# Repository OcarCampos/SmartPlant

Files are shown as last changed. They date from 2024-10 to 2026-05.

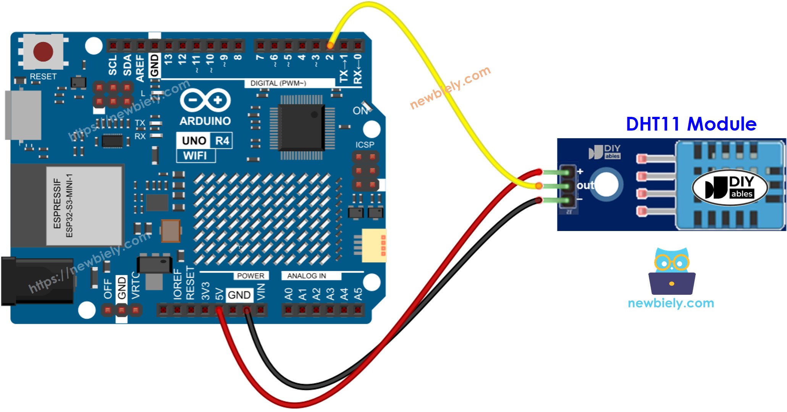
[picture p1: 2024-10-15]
Diagrams/arduino-uno-r4-dht11-module-wiring-diagram.jpg

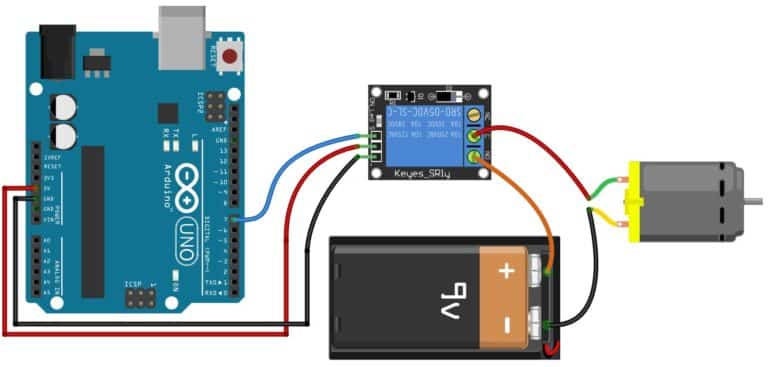
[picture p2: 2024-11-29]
Diagrams/ArduinoRelay.jpg

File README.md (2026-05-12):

# SmartPlant - Automated Garden Monitoring System




An Arduino-based garden monitoring and automated watering system. This project uses various sensors to monitor plant health and environmental conditions, with data visualization through ThingSpeak and a smart automated watering functionality.

## Table of Contents

- [Features](#features)
- [Project Status](#project-status)
- [Hardware and Software](#hardware-and-software)
  - [Hardware Requirements](#hardware-requirements)
  - [Software Dependencies](#software-dependencies)
- [Getting Started](#getting-started)
  - [Prerequisites](#prerequisites)
  - [Installation](#installation)
- [Hardware Setup](#hardware-setup)
  - [Pin Configuration](#pin-configuration)
  - [Wiring Diagrams](#wiring-diagrams)
- [How It Works](#how-it-works)
  - [Sensor Monitoring](#sensor-monitoring)
  - [Smart Watering Logic](#smart-watering-logic)
  - [ThingSpeak Integration](#thingspeak-integration)
- [Project Structure](#project-structure)
- [Development and Testing](#development-and-testing)
- [3D Printable Cases](#3d-printable-cases)
- [Contributing](#contributing)
- [License](#license)

## Features

- **Environment Monitoring**: Real-time tracking of temperature, humidity, soil moisture, and light conditions.
- **Automated Watering**: Smart watering system that activates a water pump based on soil moisture levels.
- **Data Display**: Live sensor data shown on a 16x2 LCD screen.
- **Remote Monitoring**: WiFi connectivity to send data to the ThingSpeak platform for visualization and analysis.
- **Smart Watering Cycles**: Implements timed watering cycles with absorption periods to prevent overwatering.

## Project Status

This project is considered complete and functional. All features have been implemented and tested.

**SmartPlant v2** (branch: `main`, file: `SmartPlantv2.ino`) is currently in active development and testing. It introduces a robust Arduino Nano-based monitoring station with improved sensor hardware (TEMT6000, AHT10, capacitive soil moisture) for bench validation before full deployment.

We have recently added **SmartPlantv2-uno.ino** which integrates the improved v2 sensors with the Arduino Uno R4 WiFi to report data directly to ThingSpeak, omitting the LCD and water pump for a streamlined monitoring experience.

The latest production-ready field device is **SmartPlantv2-ESP32c.ino**, designed for the ultra-compact ESP32-C3 Super Mini. This version utilizes Deep Sleep for power efficiency, features a robust debug mode, and uses an inverted sinking-LED logic for physical status indication.

## Hardware and Software

### Hardware Requirements

| Component | Purpose |
| --- | --- |
| Arduino Uno R4 WiFi | Microcontroller with built-in WiFi |
| DHT11 Sensor | Measures temperature and humidity |
| LDR (Light Dependent Resistor) | Detects light levels (Day/Night) |
| Custom Soil Moisture Sensor | Measures soil moisture content |
| 16x2 LCD Display with I2C | Displays real-time sensor data |
| Relay Module | Switches the high-voltage water pump |
| Water Pump | Waters the plant |
| Power Supply | Provides power to the system |
| Jumper Wires & Breadboard | Connects all components |

### Software Dependencies

The following Arduino libraries are required. You can install them through the Arduino IDE Library Manager.

- `WiFiS3`
- `Wire`
- `LiquidCrystal_I2C`
- `DHT`
- `ThingSpeak`

## Getting Started

### Prerequisites

- Arduino IDE installed on your computer.
- A ThingSpeak account for data visualization.

### Installation

1.  **Clone the repository:**
    ```sh
    git clone https://github.com/your-username/SmartPlant.git
    ```
2.  **Install Libraries:** Open the Arduino IDE and install the libraries listed under [Software Dependencies](#software-dependencies).
3.  **Configure Secrets:** Create a header file named `arduino_secrets.h` in the main project directory with your WiFi and ThingSpeak credentials:
    ```cpp
    #define SECRET_SSID "your_wifi_ssid"
    #define SECRET_PASS "your_wifi_password"
    #define SECRET_CH_ID your_thingspeak_channel_id
    #define SECRET_WRITE_APIKEY "your_thingspeak_write_api_key"
    ```
4.  **Hardware Assembly:** Connect the hardware components according to the [Pin Configuration](#pin-configuration) and [Wiring Diagrams](#wiring-diagrams).
5.  **Upload the Code:** Open `SmartPlant.ino` in the Arduino IDE, select the correct board and port, and upload the sketch.

## Hardware Setup

### Pin Configuration

| Component | Pin on Arduino Uno R4 | Pin Type |
| --- | --- | --- |
| DHT11 Sensor | Digital Pin 8 | Digital  |
| Light Sensor (LDR)  | Digital Pin 9 | Digital  |
| Relay Module | Digital Pin 2 | Digital  |
| Soil Moisture Sensor| Analog Pin A0 | Analog |
| LCD Display (I2C) | SDA / SCL | I2C |

### Wiring Diagrams

The `Diagrams` folder contains detailed Fritzing diagrams for connecting each component to the Arduino board. These visual guides simplify the hardware setup process.

## How It Works

### Sensor Monitoring

The system continuously reads data from the sensors:
- **DHT11**: Measures air temperature (°C) and humidity (%).
- **LDR**: Determines if it's day or night.
- **Soil Moisture Sensor**: Provides an analog value representing the soil's moisture level, which is then converted to a percentage.

### Smart Watering Logic

The watering process is triggered if the soil moisture drops below a predefined threshold (`45%`):

1.  The system initiates a **3-cycle watering process** to ensure proper soil absorption.
2.  **Watering Cycle**: The water pump runs for 5 seconds.
3.  **Absorption Pause**: The pump stops for 20 seconds to allow the water to seep into the soil.
4.  This cycle repeats three times.

The number of watering sessions is tracked and sent to ThingSpeak.

### ThingSpeak Integration

Every 15 minutes, the collected data is sent to a ThingSpeak channel for remote monitoring. The following data fields are used:

- **Field 1**: Temperature (°C)
- **Field 2**: Humidity (%)
- **Field 3**: Photoperiod (0 for Day, 1 for Night in v1) or Light Intensity (Lux in v2)
- **Field 4**: Soil Moisture (%)
- **Field 5**: Raw Soil Moisture Value
- **Field 6**: Water Pump Cycle Count (v1 only)

## Project Structure

```
SmartPlant/
├── 3D-Cases/            # STL files for 3D printable cases
├── DevModules/          # Scripts for calibration and testing
├── Diagrams/             # Fritzing wiring diagrams
├── SmartPlant.ino       # Main Arduino sketch (v1 — Arduino Uno R4 WiFi + ThingSpeak)
├── SmartPlantv2.ino     # Test-bench sketch (v2 — Arduino Nano + sensor validation)
├── SmartPlantv2-uno.ino # Integrated sketch (v2 sensors + Arduino Uno R4 WiFi + ThingSpeak)
├── SmartPlantv2-ESP32c.ino # Production field sketch (ESP32-C3 Super Mini + ThingSpeak + Deep Sleep)
├── arduino_secrets.h.example # Example secrets file
└── README.md             # This file
```

## SmartPlant v2 — Test Bench

For v2 hardware validation (Arduino Nano + sensors), open `SmartPlantv2.ino` in the Arduino IDE. This version is optimized for stability and modularity.

**Key Updates:**
- **Modular Data**: Uses C++ `structs` to return multiple sensor values for cleaner code.
- **Improved Logging**: Centralized horizontal data log for easier real-time monitoring.
- **Capacitive Sensing**: Switched to capacitive soil monitoring (corrosion-resistant).

**Pin configuration (v2):**

| Component | Pin on Arduino Nano | Type |
|---|---|---|
| TEMT6000 Light | A0 | Analog |
| AHT10 (I2C) | A4 (SDA) / A5 (SCL) | I2C |
| Capacitive Soil Moisture | A1 | Analog |

**Horizontal Data Format:**
`[SmartPlant v2] Data -> Temp: 24.5°C | Hum: 45.2% | Light: 150 lux | Soil Raw: 420`

## SmartPlant v2 — ESP32-C3 Production Device

The `SmartPlantv2-ESP32c.ino` sketch is the highly optimized, production-ready version designed to run on the **ESP32-C3 Super Mini**. It is designed to be deployed in the field using minimal power.

**Key Features:**
- **Deep Sleep**: The device sleeps for 15 minutes between ThingSpeak updates to conserve power.
- **Sinking LED Logic**: Uses an inverted logic (LOW = ON, HIGH = OFF) for Green, Yellow, and Red status LEDs.
- **Debug Mode**: A toggleable `DEBUG` constant allows for rich Serial Monitor logging during bench testing.
- **WiFi Power Fix**: Includes a critical fix (`WiFi.setTxPower(WIFI_POWER_8_5dBm)`) required for the ESP32-C3 Super Mini to connect reliably to Wi-Fi without crashing due to power spikes.

**Pin configuration (ESP32-C3):**

| Component | Pin on ESP32-C3 Super Mini | Type |
|---|---|---|
| TEMT6000 Light | GPIO 0 (ADC1) | Analog |
| AHT10 (I2C) | GPIO 8 (SDA) / GPIO 9 (SCL) | I2C |
| Green LED | GPIO 4 | Digital (Sinking) |
| Yellow LED | GPIO 5 | Digital (Sinking) |
| Red LED | GPIO 6 | Digital (Sinking) |

> [!WARNING]
> **Avoid Strapping Pins for Analog Sensors (GPIO 2, 8, 9):**
> Do not use **GPIO 2** for analog sensors like the TEMT6000. GPIO 2 is a "strapping pin" used to determine the chip's boot mode, and the Super Mini board features a physical hardwired pull-up resistor (typically 10k) on this pin to ensure proper booting. Connecting a sensor to GPIO 2 creates a voltage divider that completely skews the readings (e.g., forcing a light sensor to read ~1.6V even in pitch black). Always use a safe, unencumbered ADC1 pin like **GPIO 0**, **GPIO 1**, or **GPIO 3** for analog inputs.

> [!WARNING]
> **ESP32-C3 Super Mini Wi-Fi Antenna Issue:**
> This specific microcontroller board has a known hardware limitation with its ceramic antenna and internal voltage regulator. When attempting to connect to Wi-Fi at default TX power levels, the sudden current draw (300-500mA) can cause the Wi-Fi radio to brown-out and fail to connect indefinitely. To solve this, the code explicitly limits the transmit power using `WiFi.setTxPower(WIFI_POWER_8_5dBm)`. If you port this code to a different ESP32 board, you may safely remove or increase this limit.

## Sensor Calibration

To get accurate readings in your final deployment, consider the following calibration steps:

### 1. Capacitive Soil Moisture (CRITICAL)
Every capacitive sensor is different. You need to find your specific "Dry" and "Wet" values:
1.  Hold the sensor in **Air** and record the `Soil Raw` value (e.g., `600`).
2.  Submerge the sensor in **Water** (up to the white line) and record the value (e.g., `250`).
3.  Use the `map()` function in your code to convert raw values to 0-100%.

### 2. TEMT6000 Light Sensor
The lux calculation (`voltage * 200.0`) is an approximation. For better accuracy:
- Compare it against a lux meter app on your smartphone and adjust the multiplier (`200.0`) until the values match.

### 3. AHT10 Temp/Humidity
- This sensor is factory-calibrated. No user calibration is typically required.

## Development and Testing

The `DevModules` directory contains various scripts for calibrating sensors, testing hardware components, and verifying connectivity. These are invaluable for initial setup and troubleshooting.

## 3D Printable Cases

The `3D-Cases` folder contains STL files for custom enclosures for the project's components, sourced from [Printables](https://www.printables.com). Using these cases provides protection and a clean, professional look to the final assembly.

## Contributing

Contributions are welcome! Feel free to submit issues, fork the repository, and create pull requests for any improvements.

## License

This project is open source and available under the [MIT License](LICENSE).

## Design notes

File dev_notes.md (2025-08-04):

# SmartPlant Refactoring Notes

This document outlines potential improvements for the `SmartPlant.ino` sketch to enhance its functionality, efficiency, and reliability.

## Key Areas for Improvement

### 1. Critical Bug: `watering_check()` Not Called
- **Issue**: The `watering_check()` function, which handles the automated watering logic, is defined but never called within the main `loop()`.
- **Impact**: The core feature of automated watering is currently non-functional.
- **Solution**: Add a call to `watering_check()` inside the `loop()` function.

### 2. Replace Blocking `delay()` Calls
- **Issue**: The code extensively uses `delay()`, which blocks the microcontroller from performing other tasks, making the system unresponsive.
- **Impact**: While a `delay()` is active, the Arduino cannot read sensors, update the LCD, or check the WiFi connection.
- **Solution**: Refactor the code to use a non-blocking timing mechanism with the `millis()` function. This will allow the system to handle multiple tasks concurrently.

### 3. Simplify Repetitive Code
- **Issue**: The `watering_check()` function contains repeated blocks of code for its three watering cycles.
- **Impact**: This makes the code harder to read and maintain. If the watering logic needs to be changed, it must be updated in three separate places.
- **Solution**: Use a `for` loop to iterate through the watering cycles. This will make the code more concise and easier to manage.

### 4. Improve LCD Display Logic
- **Issue**: The current implementation cycles through each sensor reading on the LCD with a delay between each screen. This is slow and inefficient.
- **Impact**: The user has to wait to see all the relevant data.
- **Solution**: Redesign the LCD layout to display multiple sensor readings on the screen simultaneously. The display can be updated periodically without long delays.

### 5. Add Sensor Error Handling
- **Issue**: The code does not validate the readings from the DHT11 sensor. Sensors can occasionally return invalid data (e.g., `NaN` - Not a Number).
- **Impact**: Invalid data could lead to incorrect logic or display errors.
- **Solution**: Add checks to ensure the sensor readings for temperature and humidity are valid before using them.

### 6. General Readability and Maintenance
- **Issue**: While the code is functional, it could benefit from better organization.
- **Solution**:
    - Group related constants and variables together.
    - Break down large functions into smaller, more specialized helper functions.
    - Add more descriptive comments to explain complex parts of the code.

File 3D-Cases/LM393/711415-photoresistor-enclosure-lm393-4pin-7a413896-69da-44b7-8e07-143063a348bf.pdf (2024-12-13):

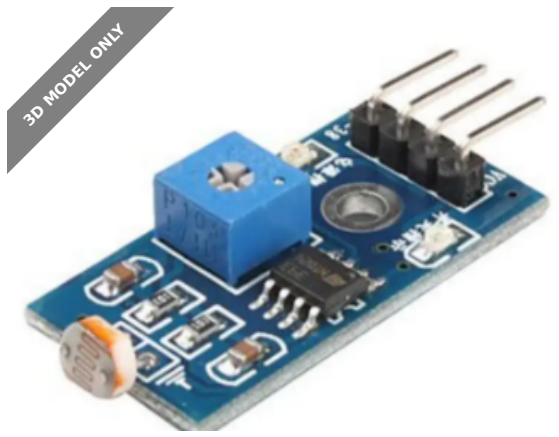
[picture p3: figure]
3D MODEL ONLY

## Model files

## Summary

Small enclosure for the Sensor LM393 (4pin)

Hobby & Makers (https://printables.com/model?categoryId=48) > Electronics (https://printables.com/model?categoryId=52)

Tags: arduino | iot | photoresistor

Presenting a two-part model consisting of a case and cap, tailored for the LM393 (4-pin) sensor. Streamline your assembly process with this userfriendly design—no supports required. Simply slide the LM393 sensor into the case and effortlessly snap on the cap for a secure fit. Securing the enclosure to any surface using two screws.

- Case

t (https://printables.com/@tomk0014_1389362) tomk0014 (https://printables.com/@tomk0014_1389362)

## Photoresistor Enclosure - LM393

## (4pin)

VIEW IN BROWSER (https://printables.com/model/711415-photoresistor-enclosure-lm393-4pin)

updated 19. 1. 2024 | published 19. 1. 2024

photoresistor_case.stl

- Cap

## License

This work is licensed under a
Creative Commons (4.0 International License)

Attribution-ShareAlike (http://creativecommons.org/licenses/by-sa/4.0/)

✖ | Sharing without ATTRIBUTION
✔ | Remix Culture allowed
✔ | Commercial Use
✔ | Free Cultural Works
✔ | Meets Open Definition

photoresistor_cap.stl

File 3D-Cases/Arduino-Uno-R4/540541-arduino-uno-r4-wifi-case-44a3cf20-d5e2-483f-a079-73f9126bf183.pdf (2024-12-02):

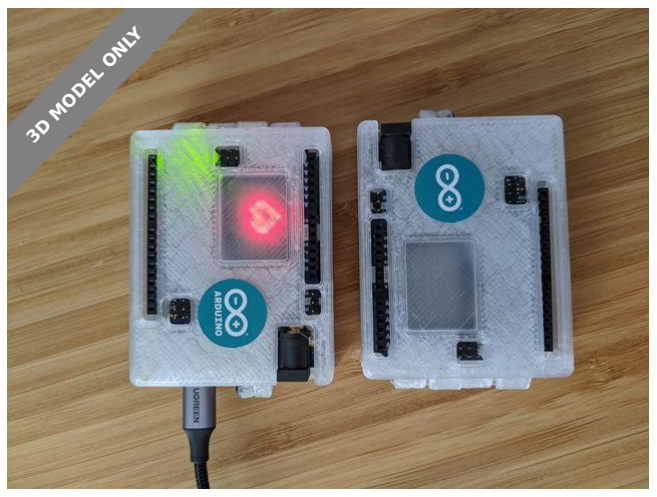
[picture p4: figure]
3D MODEL ONLY

Summary

Hinged case with all the I/O connectors accessible with the case closed.

Hobby & Makers (https://printables.com/model?categoryId=48) > Electronics (https://printables.com/model?categoryId=52)

Tags: case | wifi | arduino | uno | r4

A hinged case for the new Arduino Uno R4 WiFi with all the I/O connectors accessible when the case is closed.

The second version has the reset push button accessible from the top or the side of the cover.

You need 1.75 filament for the back hinge, a M2x6 screw for the front hinge and 4 thermoplastic inserts for 4 M3x6 screws for the board itself.

If printed using a transparent filament, the LED matrix is visible with the case closed.

Printed with clear transparent Pusament PETG using a 0.6 nozzle.

There are supports required for the hinges; I used organic.

I'll add the OpenSCAD source file after cleaning-up if there is interest.

p (https://printables.com/@pfelecan_266981) pfelecan (https://printables.com/@pfelecan_266981)

Arduino Uno R4
WiFi Case

VIEW IN BROWSER (https://printables.com/model/540541-arduino-uno-r4-wifi-case)

updated 15. 8. 2023 | published 15. 8. 2023

Model files

License

This work is licensed under a GNU

General Public License v3.0 (https://www.gnu.org/licenses/gpl-3.0.html)

✖ | Sharing without ATTRIBUTION
✔ | Remix Culture allowed
✔ | Commercial Use
✔ | Meets Open Definition
ℹ | Share under the same license

unor4wifi-bottom.3mf

unor4wifi-bottom.stl

unor4wifi-top.3mf

unor4wifi-top.stl

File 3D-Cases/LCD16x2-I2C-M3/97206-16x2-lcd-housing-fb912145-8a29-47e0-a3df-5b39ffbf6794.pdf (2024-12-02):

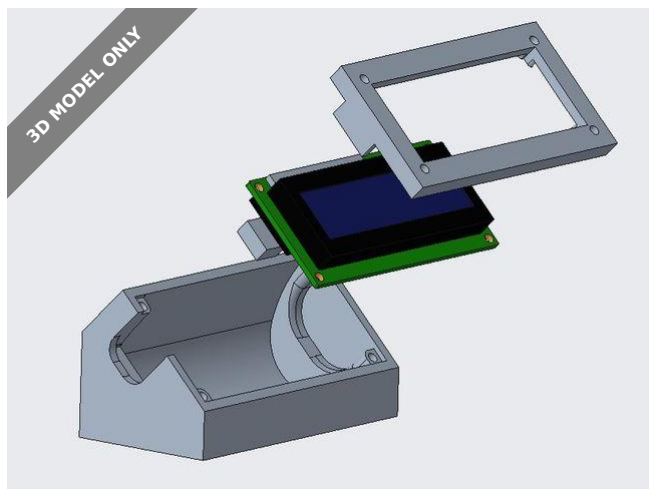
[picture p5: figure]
3D MODEL ONLY

# Summary

Housing for 16x2 LCDs with an I2C controller on the back.

Hobby & Makers (https://www.printables.com/model?categoryId=48) > Electronics (https://www.printables.com/model?categoryId=52)

Tags: housing | lcd | lcdmount | lcdcase | 16x2 | lcd16x2
lcddisplay | 16x2lcd

Housing for 16x2 LCDs with an I2C controller on the back. The front panel is universal and fits all versions of the back-part (45° or 90°). Select the correct hole diameter for your LCD screen (M2 or M3) and the display cutout (big or small).

For LCDs with the following measurements:

M2 or M3 holes
hole distance 75x31mm
board dimensions 80x36mm
display cutout dimensions 72x27mm (big) or 71x24mm (small)

Requirements:

4pcs M2x20 or M3x20 screws for the front panel
2pcs M3 or M4 screws for mounting the back housing to your desired location

dadul96 (https://www.printables.com/social/192589/about)

# 16x2 LCD Housing

VIEW IN BROWSER (https://www.printables.com/model/97206-16x2-lcd-housing)

updated 12. 4. 2022 | published 18. 12. 2021

•
•
•
•

•
•

# Model files

Find source .stl files on Thingiverse.com (https://www.thingiverse.com/thing:3839594)

16x2_front_small_m2.stl

16x2_front_small_m3.stl

16x2_front_big_m3.stl

16x2_back_90deg_m3.stl

16x2_back_90deg_m2.stl

16x2_back_45deg_m3.stl

16x2_back_45deg_m2.stl

16x2_front_big_m2.stl

# License

This work is licensed under a
Creative Commons (4.0 International License)

Attribution-ShareAlike (http://creativecommons.org/licenses/by-sa/4.0/)

✖ | Sharing without ATTRIBUTION
✔ | Remix Culture allowed
✔ | Commercial Use
✔ | Free Cultural Works
✔ | Meets Open Definition

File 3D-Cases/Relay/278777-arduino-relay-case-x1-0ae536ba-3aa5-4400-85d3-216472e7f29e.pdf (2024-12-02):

## ARDUINO RELAY CASE X1

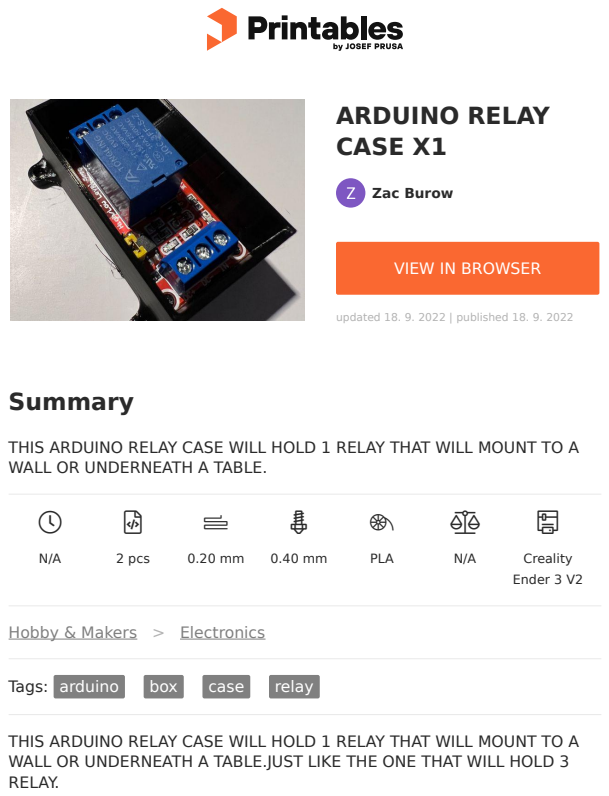
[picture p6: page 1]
2 pcs; PLA; Creality; Ender 3 V2; Summary; Tags: arduino; box; case; relay; Zac Burow; updated 18. 9. 2022 | published 18. 9. 2022

VIEW IN BROWSER (https://www.printables.com/model/278777-arduino-relay-case-x1)

THIS ARDUINO RELAY CASE WILL HOLD 1 RELAY THAT WILL MOUNT TO A
WALL OR UNDERNEATH A TABLE.

Hobby & Makers (https://www.printables.com/model?categoryId=48) > Electronics (https://www.printables.com/model?categoryId=52)

WALL OR UNDERNEATH A TABLE.JUST LIKE THE ONE THAT WILL HOLD 3
RELAY.

## Model files

## Print files

h PLA | k 0.40 mm | f 0.20 mm | 1.00 hrs | 3 g
h PLA | k 0.40 mm | f 0.20 mm | 1.00 hrs | 17 g

Find source .stl files on Thingiverse.com (https://cad.onshape.com/)

## License

This work is licensed under a
Creative Commons (4.0 International License)

Attribution (http://creativecommons.org/licenses/by/4.0/)

✖ | Sharing without ATTRIBUTION
✔ | Remix Culture allowed
✔ | Commercial Use
✔ | Free Cultural Works
✔ | Meets Open Definition

arduino-relat-top-x1.stl

arduino-relay-bottom-x1.stl

arduino-relat-top-x1.gcode

arduino-relay-bottom-x1.gcode

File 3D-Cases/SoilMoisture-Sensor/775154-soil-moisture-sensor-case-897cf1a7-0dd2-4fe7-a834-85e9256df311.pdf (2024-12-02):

## Soil moisture

## sensor case

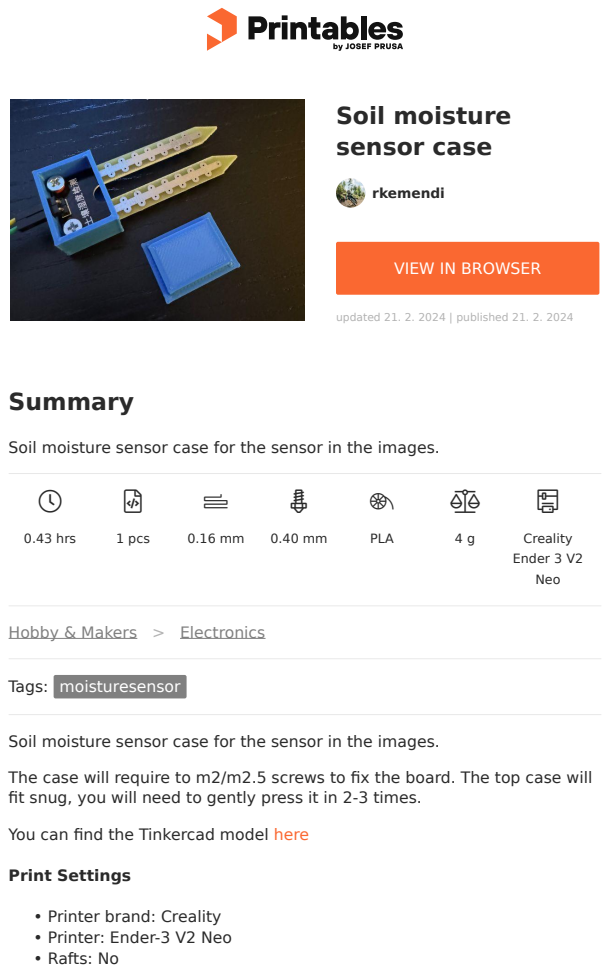
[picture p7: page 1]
0.43 hrs; 1 pcs; PLA; Creality; Ender 3 V2; Neo; Summary; Hobby & Makers; Electronics; Tags: moisturesensor; Print Settings; Printer brand: Creality; Printer: Ender-3 V2 Neo; Rafts: No; rkemendi; updated 21. 2. 2024 | published 21. 2. 2024

VIEW IN BROWSER (https://printables.com/model/775154-soil-moisture-sensor-case)

Soil moisture sensor case for the sensor in the images.

The case will require to m2/m2.5 screws to fix the board. The top case will
fit snug, you will need to gently press it in 2-3 times.

You can find the Tinkercad model here (https://www.tinkercad.com/things/4SNNSqMVyUa-hygrometer-v13)

# Model files

## Print files

Supports: No
Resolution: 0.16

Infill: 20%

Filament brand: Creality

Filament color: blue

Filament material: pla

h PLA | k 0.40 mm | f 0.16 mm | 0.43 hrs | 4 g

## License

This work is licensed under a

Creative Commons (4.0 International License) (http://creativecommons.org/licenses/by-sa/4.0/)

•

•

•

•

•

•

hygrometer-v13.stl

hygrometer-v13-top.stl

hygrometer-v13-bottom.stl

hygrometer-v13.gcode

Attribution-ShareAlike (http://creativecommons.org/licenses/by-sa/4.0/)

✖ | Sharing without ATTRIBUTION
✔ | Remix Culture allowed
✔ | Commercial Use
✔ | Free Cultural Works
✔ | Meets Open Definition

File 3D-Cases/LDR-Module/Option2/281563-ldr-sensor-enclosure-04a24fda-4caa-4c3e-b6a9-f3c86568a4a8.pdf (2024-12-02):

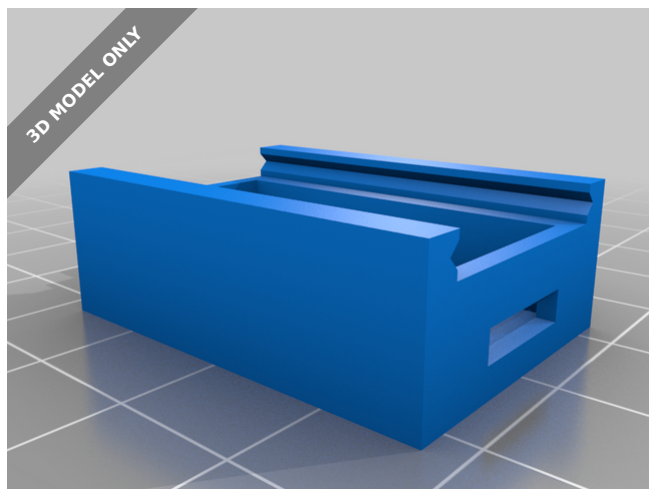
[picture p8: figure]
3D MODEL ONLY

## Summary

A recent project I was making required an LDR and it was very cheap to purchase a bulk load already on small boards...

Hobby & Makers (https://www.printables.com/model?categoryId=48) > Electronics (https://www.printables.com/model?categoryId=52)

Tags: lightsensor

A recent project I was making required an LDR and it was very cheap to purchase a bulk load already on small boards that use the LM393 & output Analog & Digital signals, from Ali Express:

https://www.aliexpress.com/item/1959461876.html

I designed a small enclosure in FreeCAD to house the sensor.

There is also access in the base to the sensitivity adjuster.

Secured with a No.4 x 1/4" self tapper.

No fancy filament, just cheap SUNLU PLA from AliExpress.

The dropdown box does not have my exact printer but it is:

Anycubic Mega Zero 2

Hotend @ 190°C

1 (https://www.printables.com/social/374726/about) 1CM69 (https://www.printables.com/social/374726/about)

## LDR Sensor Enclosure

VIEW IN BROWSER (https://www.printables.com/model/281563-ldr-sensor-enclosure)

updated 23. 9. 2022 | published 23. 9. 2022

## Model files

Bed @ 60°C

Print Settings

Printer Brand:

Anycubic

Printer:

All-metal Mega

Rafts:

No

Supports:

Yes

Resolution:

0.12

Infill:

25%

Filament: SUNLU PLA Black

Category: Electronics

Find source .stl files on Thingiverse.com (https://www.thingiverse.com/thing:4667005)

cover.stl

base.stl

## License

This work is licensed under a
Creative Commons (4.0 International License)

Attribution (http://creativecommons.org/licenses/by/4.0/)

✖ | Sharing without ATTRIBUTION
✔ | Remix Culture allowed
✔ | Commercial Use
✔ | Free Cultural Works
✔ | Meets Open Definition

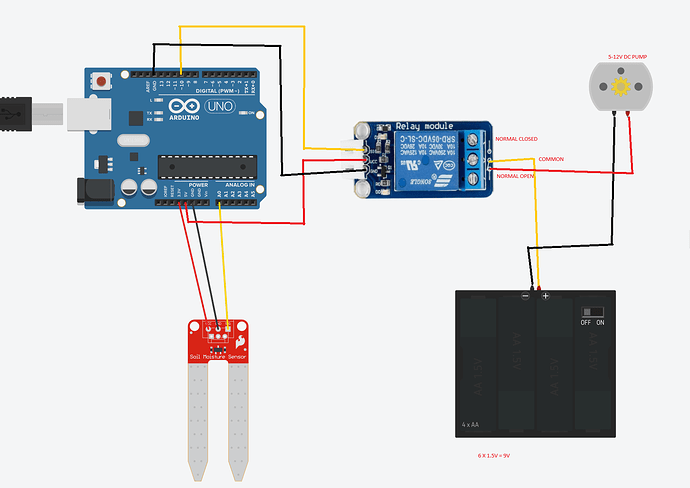
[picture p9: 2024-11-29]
Diagrams/PumpRelay.png

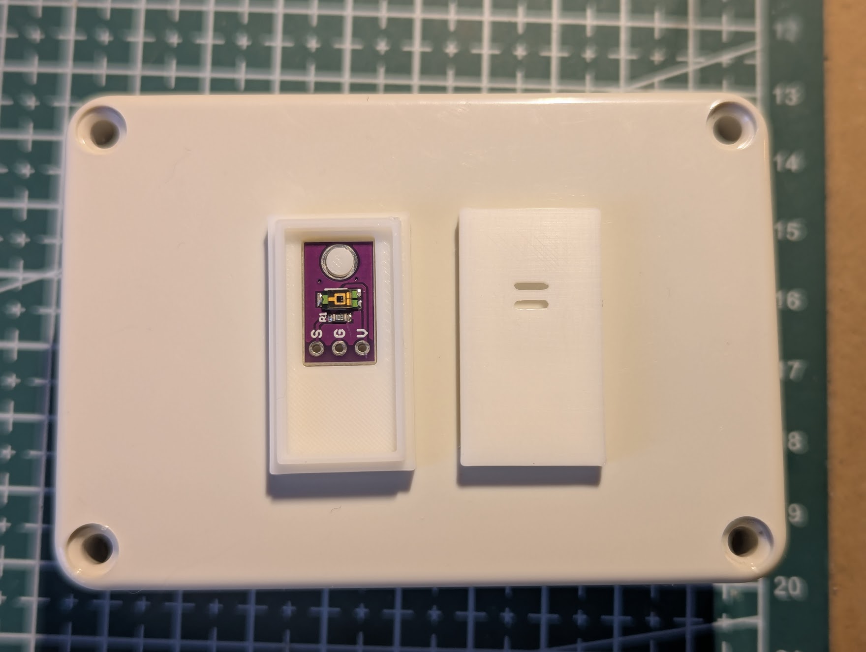
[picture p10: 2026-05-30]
3D-Cases/TEMT6000/Pic 1.jpg

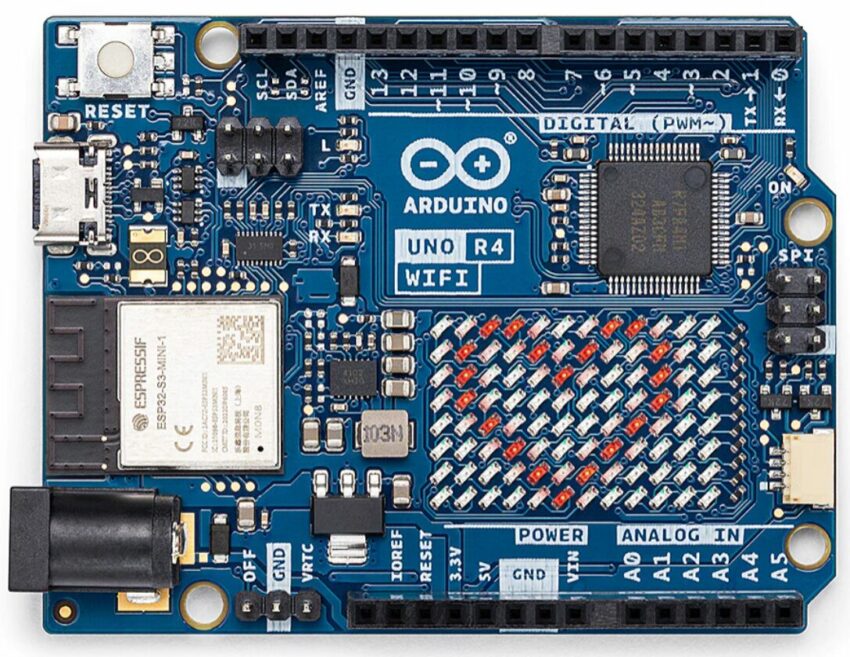
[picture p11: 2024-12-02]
Diagrams/Arduino-UNO-R4-WiFi-1-850x657.jpg

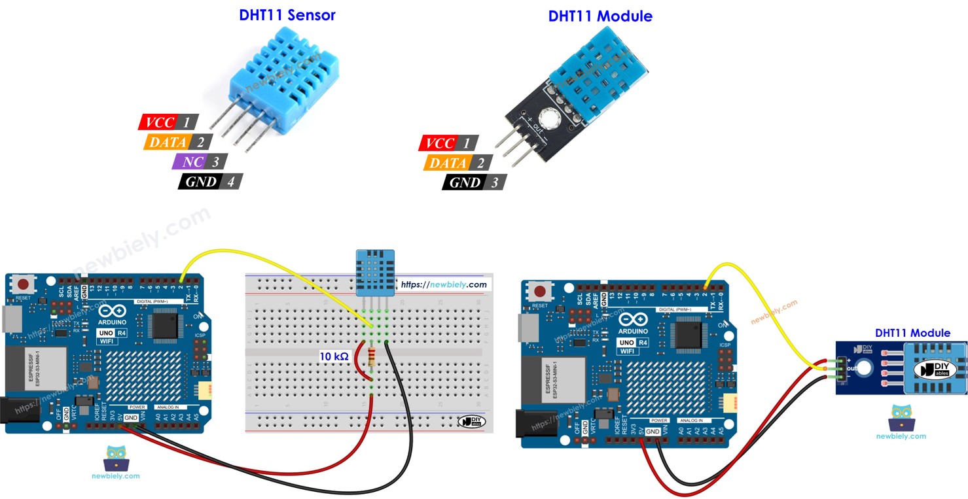
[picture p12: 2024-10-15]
Diagrams/dht11-arduino.jpg

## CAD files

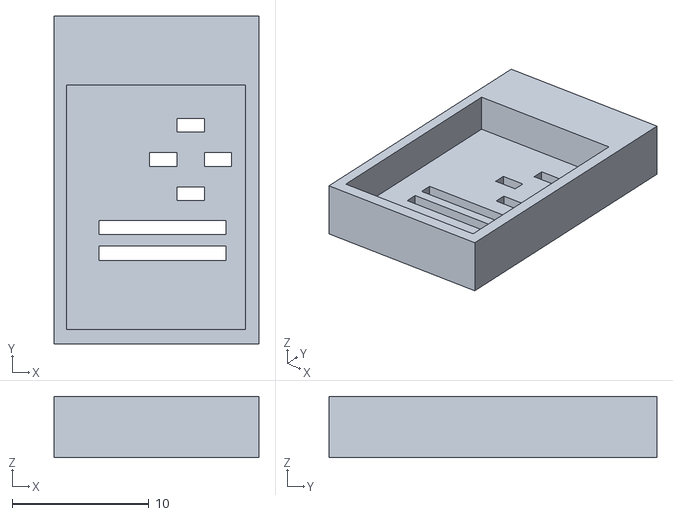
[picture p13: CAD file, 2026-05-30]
3D-Cases/AHT10/aht20housingfront_v3.stl
15.0 x 24.0 x 4.50

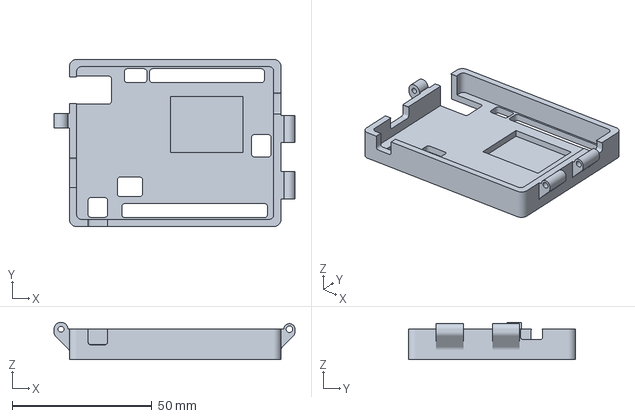
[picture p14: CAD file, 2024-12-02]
3D-Cases/Arduino-Uno-R4/UnoR4WiFi-top.3mf
86.2 x 59.8 x 13.4 mm

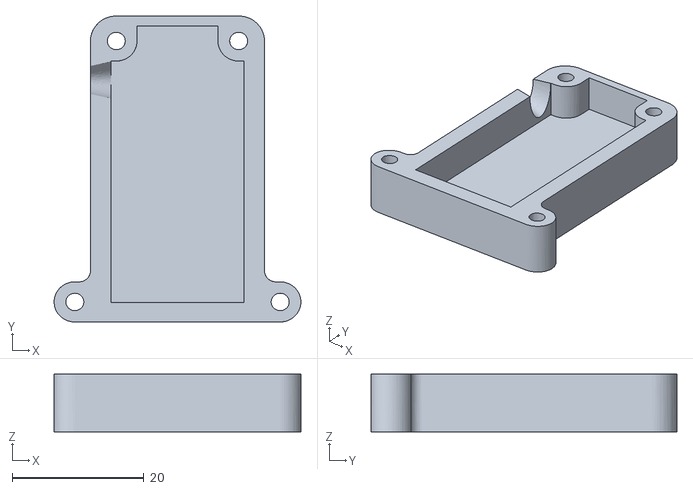
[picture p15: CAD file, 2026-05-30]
3D-Cases/capacitive-soil-moisture/Lid3.stl
37.5 x 46.5 x 8.80

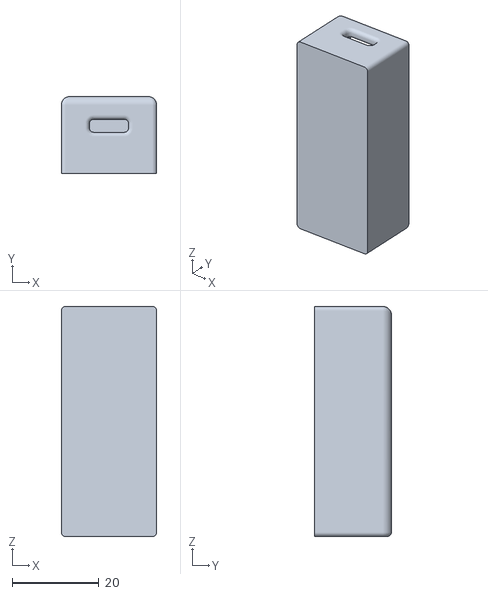
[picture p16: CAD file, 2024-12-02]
3D-Cases/DHT11-Sensor/Arduino DHT11 Case Chassi.STL
22.0 x 17.8 x 53.0

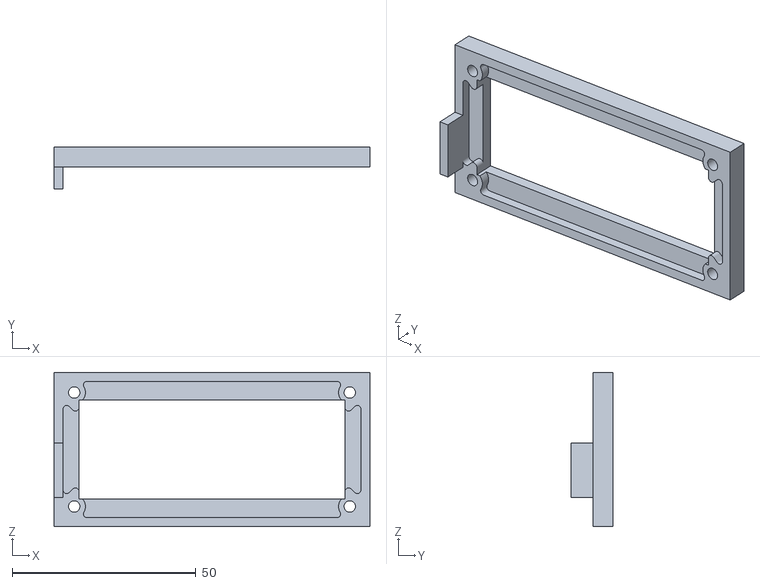
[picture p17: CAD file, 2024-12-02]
3D-Cases/LCD16x2-I2C-M3/16x2_front_big_m3.stl
86.0 x 11.5 x 42.0

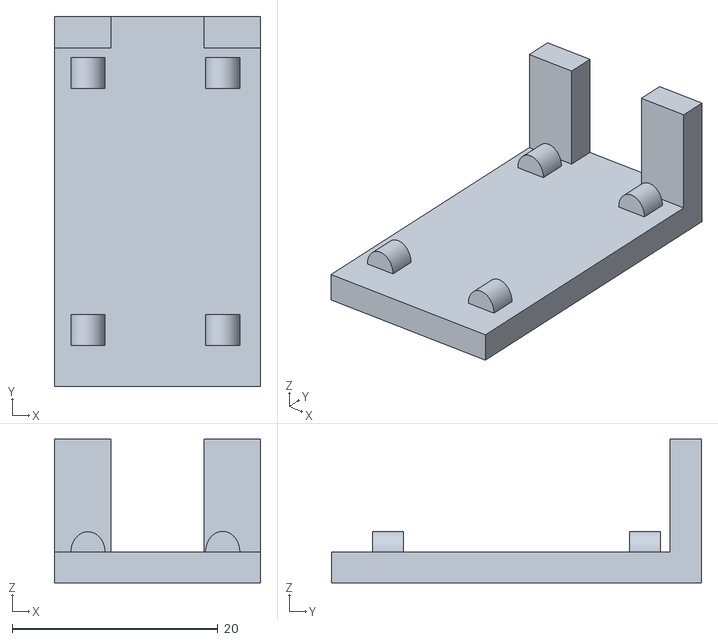
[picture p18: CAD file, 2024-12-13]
3D-Cases/LDR-Module/Option1/photoresistor_cap.stl
20.1 x 36.0 x 14.0

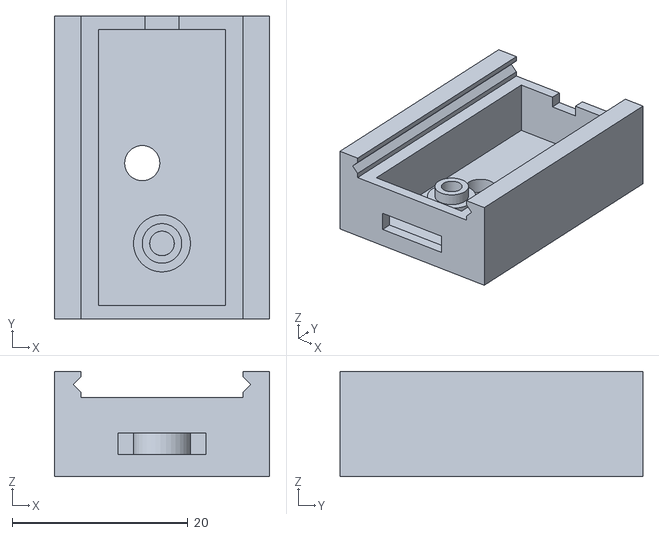
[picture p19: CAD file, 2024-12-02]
3D-Cases/LDR-Module/Option2/Base.stl
24.5 x 34.5 x 12.0

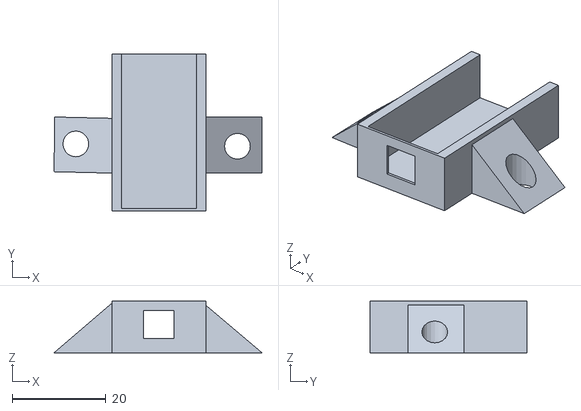
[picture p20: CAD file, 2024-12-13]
3D-Cases/LM393/photoresistor_case.stl
44.4 x 33.5 x 11.0

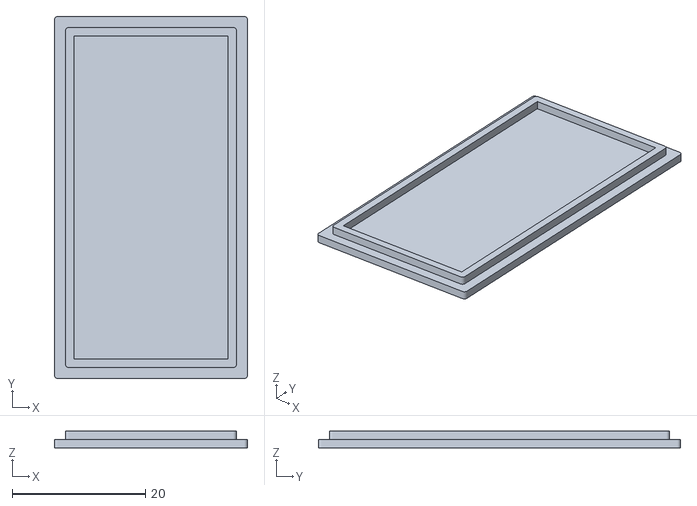
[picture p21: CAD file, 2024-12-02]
3D-Cases/Relay/ARDUINO RELAT TOP X1.stl
29.0 x 54.4 x 2.54

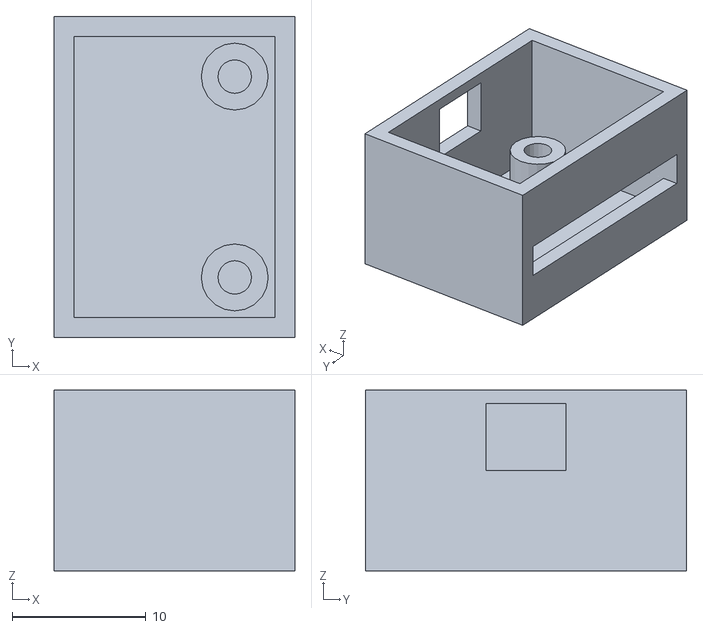
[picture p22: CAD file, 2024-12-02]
3D-Cases/SoilMoisture-Sensor/hygrometer-v13-bottom.stl
18.0 x 24.0 x 13.5

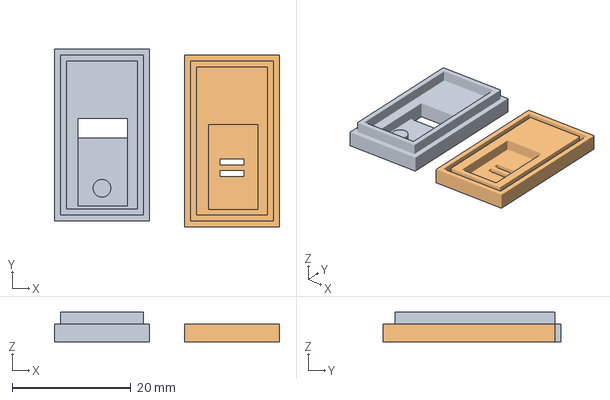
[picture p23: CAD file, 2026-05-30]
3D-Cases/TEMT6000/Temt6000.3mf
38.0 x 30.0 x 5.00 mm
Temt6000_base5.stl
Temt6000_cover5.stl

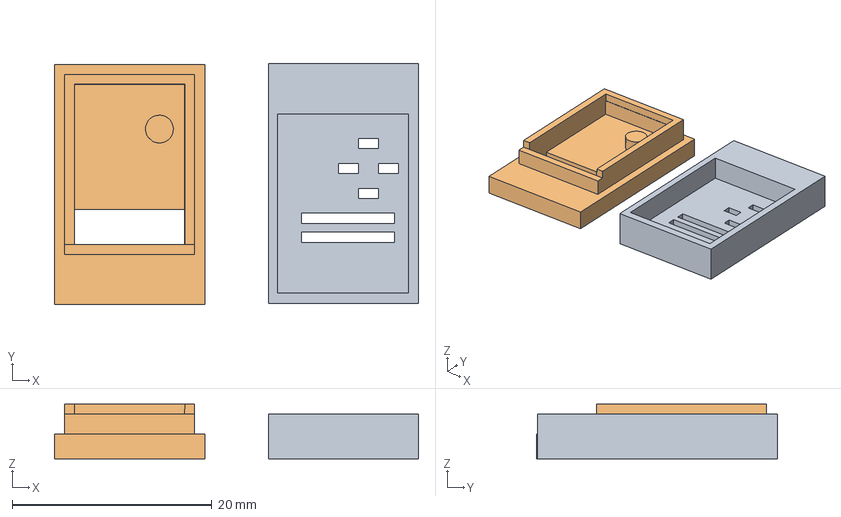
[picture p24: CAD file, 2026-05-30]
3D-Cases/AHT10/AHT10.3mf
36.4 x 24.1 x 5.50 mm
aht20housingfront_v3.stl
aht20housingback_v2.stl

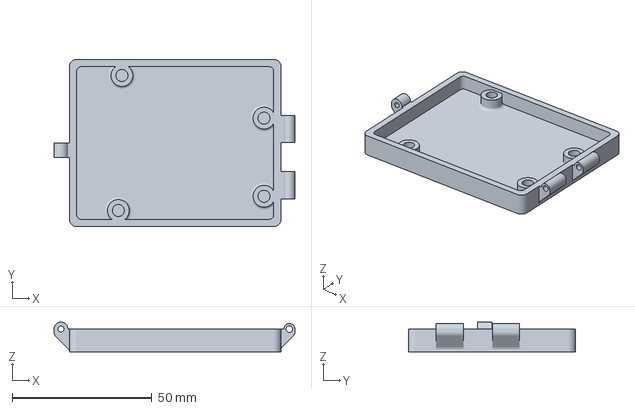
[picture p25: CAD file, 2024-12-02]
3D-Cases/Arduino-Uno-R4/UnoR4WiFi-bottom.3mf
86.2 x 59.8 x 10.7 mm

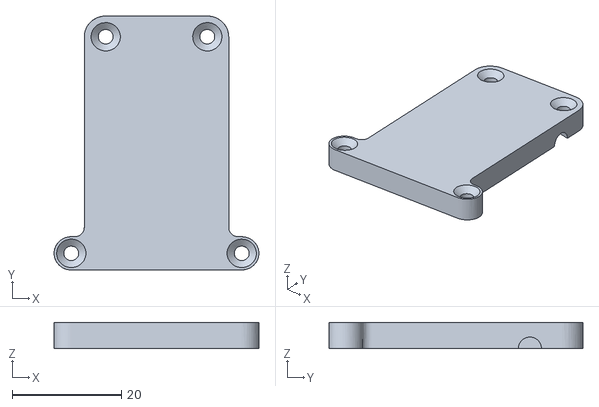
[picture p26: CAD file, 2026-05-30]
3D-Cases/capacitive-soil-moisture/Lid2.stl
37.5 x 46.5 x 4.80

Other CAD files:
3D-Cases/DHT11-Sensor/Arduino DHT11 Case Cover.STL
3D-Cases/LCD16x2-I2C-M3/16x2_back_45deg_m3.stl
3D-Cases/LDR-Module/Option2/Cover.stl
3D-Cases/AHT10/aht20housingback_v2.stl
3D-Cases/Arduino-Uno-R4/UnoR4WiFi-bottom.stl
3D-Cases/Arduino-Uno-R4/UnoR4WiFi-top.stl
3D-Cases/LCD16x2-I2C-M3/16x2_back_45deg_m2.stl
3D-Cases/LCD16x2-I2C-M3/16x2_back_90deg_m2.stl
3D-Cases/LCD16x2-I2C-M3/16x2_back_90deg_m3.stl
3D-Cases/LCD16x2-I2C-M3/16x2_front_big_m2.stl
3D-Cases/LCD16x2-I2C-M3/16x2_front_small_m2.stl
3D-Cases/LCD16x2-I2C-M3/16x2_front_small_m3.stl
3D-Cases/SoilMoisture-Sensor/hygrometer-v13-top.stl
3D-Cases/SoilMoisture-Sensor/hygrometer-v13.stl
3D-Cases/TEMT6000/Temt6000_base.stl
3D-Cases/TEMT6000/Temt6000_cover.stl
3D-Cases/capacitive-soil-moisture/Box2.stl

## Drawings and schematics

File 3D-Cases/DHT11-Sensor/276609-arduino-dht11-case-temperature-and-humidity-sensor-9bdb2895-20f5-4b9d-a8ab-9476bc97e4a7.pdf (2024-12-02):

# Arduino DHT11

## Case (Temperature

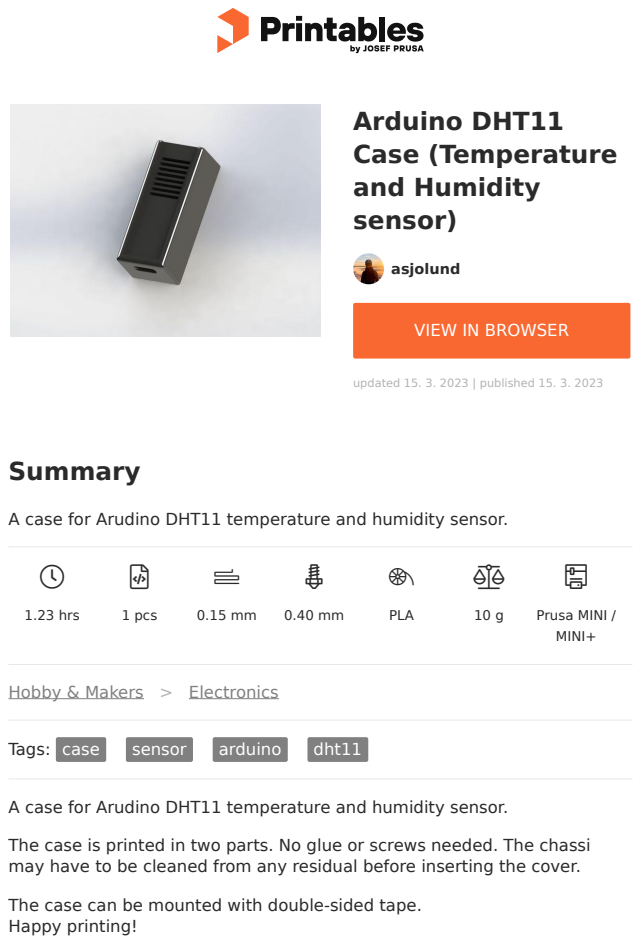
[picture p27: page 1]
1.23 hrs; 1 pcs; PLA; Prusa MINI /; MINI+; Summary; Hobby & Makers; Electronics; Tags: case; sensor; arduino; dht11; asjolund; and Humidity; sensor); updated 15. 3. 2023 | published 15. 3. 2023

VIEW IN BROWSER (https://printables.com/model/276609-arduino-dht11-case-temperature-and-humidity-sensor)

A case for Arudino DHT11 temperature and humidity sensor.

The case is printed in two parts. No glue or screws needed. The chassi
may have to be cleaned from any residual before inserting the cover.

The case can be mounted with double-sided tape.
Happy printing!

# Model files

## Print files

h PLA | k 0.40 mm | f 0.15 mm | 1.23 hrs | 10 g | d Prusa MINI / MINI+

## License

This work is licensed under a
Creative Commons (4.0 International License)

Attribution-ShareAlike (http://creativecommons.org/licenses/by-sa/4.0/)

✖ | Sharing without ATTRIBUTION
✔ | Remix Culture allowed
✔ | Commercial Use
✔ | Free Cultural Works
✔ | Meets Open Definition

arduino-dht11-case-chassi.stl

arduino-dht11-case-cover.stl

dht11-case-chassicover_015mm_pla_mini_1h14m.gcode

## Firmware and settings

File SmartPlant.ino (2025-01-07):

/*
Arduino Program for SmartPlant
Last modified: 01/07/2025
Working with Arduino Uno R4 wifi
Sensors used: DHT11, LDR, Custom Soil Moisture
LCD 16x2 with I2C adapter.
Water pump and relay used.
Connection to Wifi and ThingSpeak using secrets.h
*/

// Libraries
#include <WiFiS3.h>             // WiFi library for arduino uno
#include "arduino_secrets.h"    // Secrets file with credentials
#include <Wire.h>               // Library for I2C
#include <LiquidCrystal_I2C.h>  // Library for the LCD screen.
#include <DHT.h>                // Library for DHT11 sensor.
#include <ThingSpeak.h>         // Library for ThingSpeak

// Pins used in the card by the sensors.
#define dht11SensorPin 8     // Pin for DHT11 - Digital Pin
#define lightSensorPin 9     // Pin for Light Sensor (LDR) - Digital Pin
#define relayPin 2           // Pin for Relay - Digital Pin
#define moistSensorPin A0    // Pin for Moisture Sensor - Analog Pin

/*
 * Objects
 */

// Creates LCD object with address and 16 columns x 2 rows
LiquidCrystal_I2C lcd(0x27,16,2);       // LCD Object. 0x27 is for Arduino Uno R4 wifi as per i2c-scanner.ino.
//LiquidCrystal_I2C lcd(0x20,16,2);     // LCD Object. 0x20 is for I2C simulation in Proteus Software.
DHT dht11(dht11SensorPin, DHT11);       // DHT11 Object.

/*
 * Setting up the WiFi credentials.
 */
char ssid[] = SECRET_SSID;        // Network SSID (name) coming from secrests.h
char pass[] = SECRET_PASS;        // Network password (use for WPA, or use as key for WEP) coming from secrets.h
int status = WL_IDLE_STATUS;      // WiFi radio's status

/*
 * Setting up the ThingSpeak credentials.
 */
unsigned long myChannelNumber = SECRET_CH_ID;       // ThingSpeak Channel ID coming from secrets.h
const char * myWriteAPIKey = SECRET_WRITE_APIKEY;   // ThingSpeak Write API Key coming from secrets.h
String myStatus = "";                               // ThingSpeak status for channel
WiFiClient client;                                  // WiFi client object for ThingSpeak connection

/*
 * Calibration values for the sensors
 */

/*
 * Photo Resistor Sensor:
 * ----------------------

 * Output of sensor is either 1 or 0.
 * 0 = day time/light is on
 * 1 = night time/light is off
*/
const int day = 0;      // Value for day time.

/*
 * Soil Moisture Sensor:
 * ----------------------

 * Output of sensor is either 0 (water) or 1023 (air) by theory.
 
 * Calibration results with small pot with soil.
 *
 * 100 = full in water
 * 194 = soil 100% moistured
 * 200 = soil 100% moistured
 * 200 = soil 100% moistured
 * 330 = soil 100% moistured
 * 900 = soil 100% dry
 * 1020 = full in air (in dry soil)
 
*/
const int WaterValue = 1000;        // According to calibration
const int AirValue = 330;           // According to calibration
const int moistureLimit = 45;       // Moisture limit for watering plants. Value in % according to calibration.


/*
 * Global Variables
 */

// DHT11 Sensor
float humidity = 0.0;
float temperature = 0.0;

// LDR sensor
int photoPeriod = 0;                // Setting as day time by default.

// Soil Moisture Sensor
int soilMoistureValue = 0;
int soilMoisturePercent = 0;

// Water pump usage
int waterCycles = 0;                // Number of water cycles done by the pump

// Relay state. Usually High is on and Low is off
// In this case after testing High is off and Low is on
const byte relayOn = LOW;
const byte relayOff = HIGH;

/*
 * Time Frames in ms.
 * 1 second is 1000 milliseconds
 * 5 minutes are 300000 milliseconds
 * 10 minutes are 600000 milliseconds
 * 15 minutes are 900000 milliseconds
 * 20 minutes are 1200000 milliseconds
 * 25 minutes are 1500000 milliseconds
 * 30 minutes are 1800000 milliseconds
 * 35 minutes are 2100000 milliseconds
 * 40 minutes are 2400000 milliseconds
 * 45 minutes are 2700000 milliseconds
 * 50 minutes are 3000000 milliseconds
 * 55 minutes are 3300000 milliseconds
 * 60 minutes are 3600000 milliseconds
 */
unsigned long previousMillis = 0;           // Stores last time the information was sent to thingspeak
const int intervalStart = 5000;             // 5 seconds of welcoming message
const int intervalPause = 3000;             // 3 seconds pause for clearing the screen
const int intervalWatering = 5000;          // 5 seconds of water pump working
const int intervalWateringPause = 20000;    // 20 seconds pause for water to absorb
const int intervalThingSpeak = 900000;      // 15 minutes interval for reporting to ThingSpeak

/*
 * Setup of the program.
 */
void setup() {
    // LCD initialization
    lcd.init();                 
    lcd.backlight();         

    // Welcome message in LCD
    lcd.setCursor(0,0);
    lcd.print("Welcome to");
    lcd.setCursor(0,1);
    lcd.print("Smart Plant 1.0");
    delay(intervalStart);
    lcd.clear();

    // Connect to WiFi
    lcd.setCursor(0,0);
    lcd.print("Connecting WiFi");
    lcd.setCursor(0,1);
    lcd.print("Please wait...");
    connect_to_wifi();                  
    lcd.clear();

    // Sensors Initialization
    lcd.setCursor(0,0);
    lcd.print("Starting sensors");
    lcd.setCursor(0,1);
    lcd.print("Please wait...");
    dht11.begin();                      // DHT11 Initialization
    pinMode(lightSensorPin, INPUT);     // LDR Pin Initialization
    pinMode(relayPin, OUTPUT);          // Relay Pin Initialization
    digitalWrite(relayPin, relayOff);   // Set relay to off by default
    ThingSpeak.begin(client);           // ThingSpeak Initialization
    delay(intervalStart);
    lcd.clear();

    // Init done
    lcd.setCursor(0,0);
    lcd.print("Setup done.");
    lcd.setCursor(0,1);
    lcd.print("Starting now...");
    delay(intervalStart);              // Delay before moving on to loop
}

/*
 * Running loop.
 */
void loop() {
    // Check wifi connection. If not connected, try to reconnect.
    if (status != WL_CONNECTED) {
        lcd.setCursor(0,0);                 
        lcd.print("Reconnecting WiFi");
        lcd.setCursor(0,1);
        lcd.print("Please wait...");
        connect_to_wifi();                  
        lcd.clear();
    }

    // LCD initialization message
    lcd.setCursor(0,0);                 
    lcd.print("SmartPlant 1.0");
    lcd.setCursor(0,1);
    lcd.print("Reading sensors");
    delay(intervalPause);
    lcd.clear();

    // Reading sensor values
    sensor_readings();    

    // Printing to LCD sensor values
    lcd_screen_printing();

    // Sending sensor values to ThingSpeak
    unsigned long currentMillis = millis();
    if (currentMillis - previousMillis >= intervalThingSpeak) {
        previousMillis = currentMillis; 
        send_to_thing_speak();          
    }

    // End of loop
    delay(intervalPause);
}

/*
 * Function: sensor_readings()
 *
 * Function to read sensors values from real world.
 * All variables are global variables, so they can 
 * be used in other functions.
*/
void sensor_readings() {
    // Reading DHT11 values
    humidity = dht11.readHumidity();        
    temperature = dht11.readTemperature();  

    // Reading LDR value
    photoPeriod = digitalRead(lightSensorPin); 

    // Reading Soil Moisture value
    soilMoistureValue = analogRead(moistSensorPin);
    // Calculate moisture percentage according to calibration values
    soilMoisturePercent = map(soilMoistureValue, WaterValue, AirValue, 0, 100);     
}

/*
 * Function: lcd_screen_printing()
 *
 * Function that prints messages to the LCD screen
 * keeping the user updated.
 * All variables are global variables, so they can 
 * be used in other functions.
 */
void lcd_screen_printing() {
    // DHT11 Humidity
    lcd.setCursor(0,0);
    lcd.print("Air Humidity:");
    lcd.setCursor(0,1);
    lcd.print(humidity);
    lcd.print("%");
    delay(intervalPause);
    lcd.clear(); 

    // DHT11 Temperature
    lcd.setCursor(0,0);
    lcd.print("Temperature:");
    lcd.setCursor(0,1);
    lcd.print(temperature);
    lcd.print("*C");
    delay(intervalPause);
    lcd.clear();

    // LDR Photoperiod
    // Day time
    if (photoPeriod == day){
        lcd.setCursor(0,0);
        lcd.print("Light:");
        lcd.setCursor(0,1);
        lcd.print("Day Time.");
    }
    // Night time
    else{
        lcd.setCursor(0,0);
        lcd.print("Light:");
        lcd.setCursor(0,1);
        lcd.print("Night Time.");
    }
    delay(intervalPause);
    lcd.clear();

    // Soil Moisture Raw Value
    lcd.setCursor(0,0);
    lcd.print("Raw Moisture:");
    lcd.setCursor(0,1);
    lcd.print(soilMoistureValue);
    delay(intervalPause);
    lcd.clear();

    // Soil Moisture Percent
    lcd.setCursor(0,0);
    lcd.print("Soil Moisture:");
    lcd.setCursor(0,1);
    // Moisture Percent 0 or less
    if(soilMoisturePercent <= 0){
        lcd.print("0%");
    }
    // Moisture Percent more than 0
    else if(soilMoisturePercent >= 100){
        lcd.print("100%");
    }
    // Moisture Percent between 0 and 100
    else{
        lcd.print(soilMoisturePercent);
        lcd.print("%");
    }
    delay(intervalPause);
    lcd.clear();
}
/*
 * Function: watering_check()
 *
 * Checks if the plants needs to be watered
 * depending on the readings from the soil moisture sensor.
 *
 * If moisture is lower than moistureLimit % function will turn on the
 * relay for intervalWatering seconds and then turn off the relay.
 *
 * Function will wait for intervalWateringPause seconds to allow for
 * water to be absorved by soil before turning on the relay again
 * watering the plants a second cycle.
 *
 * Function will repeat this process a third cycle and move on.
 *
 * Total watering time is (intervalWatering * 3) + (intervalWateringPause * 2)
 */
void watering_check(){
    // If moisture is less than moistureLimit we pump water
    if(soilMoisturePercent <= moistureLimit){
        // Printing to LCD
        lcd.setCursor(0,0);
        lcd.print("Watering Plants.");
        lcd.setCursor(0,1);
        lcd.print("1st cycle...");
        // First cycle. Turn on the relay.
        digitalWrite(relayPin, relayOn);
        delay(intervalWatering);
        // Turn off the relay. Wait for water to absorb.
        digitalWrite(relayPin, relayOff);
        delay(intervalWateringPause);
        // Second cycle. Turn on the relay.
        lcd.clear();
        lcd.setCursor(0,0);
        lcd.print("Watering Plants.");
        lcd.setCursor(0,1);
        lcd.print("2nd cycle...");
        digitalWrite(relayPin, relayOn);
        delay(intervalWatering);
        // Turn off the relay. Wait for water to absorb.
        digitalWrite(relayPin, relayOff);
        delay(intervalWateringPause);
        // Third cycle. Turn on the relay.
        lcd.clear();
        lcd.setCursor(0,0);
        lcd.print("Watering Plants.");
        lcd.setCursor(0,1);
        lcd.print("3rd cycle...");
        digitalWrite(relayPin, relayOn);
        delay(intervalWatering);
        // Turn off the relay. Wait for water to absorb.
        digitalWrite(relayPin, relayOff);
        delay(intervalWateringPause);
        lcd.clear();
        lcd.setCursor(0,0);
        lcd.print("Watering Plants.");
        lcd.setCursor(0,1);
        lcd.print("Complete...");
        waterCycles++;
    }
    // Make sure relay is off if condition is not met
    else{
        digitalWrite(relayPin, relayOff);
        lcd.clear();
        lcd.setCursor(0,0);
        lcd.print("Plants Hydrated.");
        lcd.setCursor(0,1);
        lcd.print("No water needed.");
        delay(intervalPause);
        lcd.clear();
    }
}

/* 
 * Function: send_to_thing_speak()
 * 
 * Function that sends the sensor values to ThingSpeak
 * Must be configured according to the channel
 * and the API key of the channel
 *
 * Data to send to channel:
 * 0. Status message
 * 1. Temperature from DHT11 in *C	
 * 2. Humidity from DHT11 in %
 * 3. Photoperiod from LDR (0 for night time and 1 for day time)
 * 4. Moisture from Moisture sensor in %
 * 5. Raw Moisture from Moisture sensor
 * 6. Water Cycles done by the pump until now.
 */
void send_to_thing_speak() {
    // Set the fields with the values
    ThingSpeak.setField(1, temperature);
    ThingSpeak.setField(2, humidity);
    // Photoperiod is 0 for day and 1 for night
    if (photoPeriod == day){
        // 1 for lamp on.
        ThingSpeak.setField(3, 1);
    }
    else{
        // 0 for lamp off
        ThingSpeak.setField(3, 0);
    }
    ThingSpeak.setField(4, soilMoisturePercent);
    ThingSpeak.setField(5, soilMoistureValue);
    ThingSpeak.setField(6, waterCycles);

    // Set the status message
    myStatus = "Data updated successfully!";
    ThingSpeak.setStatus(myStatus);

    // Write to ThingSpeak channel.
    int x = ThingSpeak.writeFields(myChannelNumber, myWriteAPIKey);
    delay(1000); // Give some time for the connection to complete
    // Report result of connection to ThingSpeak
    if (x == 200 || x == 0) {
        lcd.setCursor(0,0);
        lcd.print("ThingSpeak has");
        lcd.setCursor(0,1);
        lcd.print("been updated.");
    }
    else {
        lcd.setCursor(0,0);
        lcd.print("ThingSpeak has");
        lcd.setCursor(0,1);
        lcd.print("NOT been updated.");
    }
    delay(intervalPause);
    lcd.clear();

    //reset water cycles to 0
    waterCycles = 0;
}

/*
 * Function: connect_to_wifi()
 *
 * Function that connects to the wifi given the credentials
 * present in arduino_secrets.h
 * Intended to work only with Arduino UNO R4 Wifi.
 */
void connect_to_wifi() {
    // Check for the WiFi module
    if (WiFi.status() == WL_NO_MODULE) {
        // don't continue
        while (true);
    }
    // Check wifi firmware version
    String fv = WiFi.firmwareVersion();
    if (fv < WIFI_FIRMWARE_LATEST_VERSION) {
        Serial.println("Please upgrade the firmware");
    }
    // Attempt to connect to WiFi network:
    while (status != WL_CONNECTED) {
        // Connect to WPA/WPA2 network:
        status = WiFi.begin(ssid, pass);
        // wait 10 seconds for connection:
        delay(10000);
    }
    // Connected now. Print out success message.
    lcd.clear();
    lcd.setCursor(0,0);
    lcd.print("WiFi Connected.");
    lcd.setCursor(0,1);
    lcd.print("Continuing...");
    delay(intervalStart);
}

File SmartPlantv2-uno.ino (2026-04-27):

/*
 * Arduino Program for SmartPlant v2
 * Working with Arduino Uno R4 wifi
 * Sensors used: AHT10, TEMT6000, Capacitive Soil Moisture
 * Connection to Wifi and ThingSpeak using secrets.h
 */

// Libraries
#include <WiFiS3.h>             // WiFi library for arduino uno
#include "arduino_secrets.h"    // Secrets file with credentials
#include <Wire.h>               // Library for I2C
#include <Adafruit_AHTX0.h>     // Library for AHT10 sensor.
#include <ThingSpeak.h>         // Library for ThingSpeak

// Pins used in the card by the sensors.
const int LIGHT_PIN = A0;    // Pin for Light Sensor (TEMT6000) - Analog Pin
const int SOIL_PIN = A1;     // Pin for Moisture Sensor - Analog Pin

/*
 * Objects
 */
Adafruit_AHTX0 aht;                     // AHT10 Object.

/*
 * Setting up the WiFi credentials.
 */
char ssid[] = SECRET_SSID;        // Network SSID (name) coming from secrests.h
char pass[] = SECRET_PASS;        // Network password (use for WPA, or use as key for WEP) coming from secrets.h
int status = WL_IDLE_STATUS;      // WiFi radio's status

/*
 * Setting up the ThingSpeak credentials.
 */
unsigned long myChannelNumber = SECRET_CH_ID;       // ThingSpeak Channel ID coming from secrets.h
const char * myWriteAPIKey = SECRET_WRITE_APIKEY;   // ThingSpeak Write API Key coming from secrets.h
String myStatus = "";                               // ThingSpeak status for channel
WiFiClient client;                                  // WiFi client object for ThingSpeak connection

/*
 * Calibration values for the sensors
 */

/*
 * Soil Moisture Sensor:
 * ----------------------
*/
const int WaterValue = 210;        // According to calibration
const int AirValue = 498;           // According to calibration

/*
 * Global Variables
 */

// AHT10 Sensor
float humidity = 0.0;
float temperature = 0.0;

// Struct to hold multiple values from AHT10
struct AHTReadings {
    float temperature;
    float humidity;
};

// LDR sensor (TEMT6000)
float luxValue = 0.0;

// Soil Moisture Sensor
int soilMoistureValue = 0;
int soilMoisturePercent = 0;

/*
 * Time Frames in ms.
 */
unsigned long previousMillis = 0;           // Stores last time the information was sent to thingspeak
const int intervalStart = 5000;             // 5 seconds of welcoming message
const int intervalPause = 3000;             // 3 seconds pause for clearing the screen
const int intervalThingSpeak = 900000;      // 15 minutes interval for reporting to ThingSpeak

/*
* Debug mode
*/
const bool DEBUG_MODE = false;            // Debug mode for printing values to serial monitor


/*
 * Setup of the program.
 */
void setup() {
    Serial.begin(9600);
    
    Serial.println("[SmartPlant v2] Welcome!");
    delay(intervalStart);

    // Connect to WiFi
    Serial.println("[SmartPlant v2] Connecting WiFi. Please wait...");
    connect_to_wifi();                  

    // Sensors Initialization
    Serial.println("[SmartPlant v2] Starting sensors. Please wait...");
    
    if (aht.begin()) {
        Serial.println("[SmartPlant v2] AHT10 initialized successfully");
    } else {
        Serial.println("[SmartPlant v2] AHT10 initialization failed");
    }

    pinMode(LIGHT_PIN, INPUT);          // Light Pin Initialization
    pinMode(SOIL_PIN, INPUT);           // Soil Pin Initialization
    ThingSpeak.begin(client);           // ThingSpeak Initialization
    delay(intervalStart);

    // Init done
    Serial.println("[SmartPlant v2] Setup done. Starting now...");
    delay(intervalStart);              // Delay before moving on to loop
    Serial.println("[SmartPlant v2] Reading sensors now...");
}

/*
 * Running loop.
 */
void loop() {
    // Check wifi connection. If not connected, try to reconnect.
    if (status != WL_CONNECTED) {
        Serial.println("[SmartPlant v2] Reconnecting WiFi. Please wait...");
        connect_to_wifi();                  
    }

    // Reading sensor values
    sensor_readings();    

    if (DEBUG_MODE){
        // Print to Serial for debugging
        Serial.print("[SmartPlant v2] Data -> ");
        Serial.print("Temp: "); Serial.print(temperature, 1); Serial.print("C | ");
        Serial.print("Hum: ");  Serial.print(humidity, 1);    Serial.print("% | ");
        Serial.print("Light: "); Serial.print(luxValue, 0);   Serial.print(" lux | ");
        Serial.print("Soil Raw: "); Serial.print(soilMoistureValue); Serial.print(" | ");
        Serial.print("Soil Moist: "); Serial.print(soilMoisturePercent); Serial.println("%");
    }

    // Sending sensor values to ThingSpeak
    unsigned long currentMillis = millis();
    if (currentMillis - previousMillis >= intervalThingSpeak) {
        previousMillis = currentMillis; 
        send_to_thing_speak();          
    }

    // End of loop
    delay(intervalPause);
}

AHTReadings AHT10_READ(){
    sensors_event_t hum, temp;
    aht.getEvent(&hum, &temp);  // Read temperature and humidity

    // Create a readings object and populate it
    AHTReadings readings;
    readings.temperature = temp.temperature;
    readings.humidity = hum.relative_humidity;

    return readings; // Return the whole object
}

float TEMT6000_READ(){
    int analogValue = analogRead(LIGHT_PIN);        // Read TEMT6000 analog value (0-1023)
    float voltage = analogValue * (5.0 / 1023.0);   // Convert to voltage (0-5V)
    float lux = voltage * 200.0;  // Approximate conversion factor
    return lux;
}

int SOIL_MOISTURE_READ(){
    // Raw data from sensor
    int soilValue = analogRead(SOIL_PIN);
    return soilValue;
}

/*
 * Function: sensor_readings()
 */
void sensor_readings() {
    // Reading AHT10 values
    AHTReadings data = AHT10_READ();
    humidity = data.humidity;        
    temperature = data.temperature;  

    // Reading Light value
    luxValue = TEMT6000_READ(); 

    // Reading Soil Moisture value
    soilMoistureValue = SOIL_MOISTURE_READ();
    // Calculate moisture percentage according to calibration values
    soilMoisturePercent = map(soilMoistureValue, AirValue, WaterValue, 0, 100);     
}

/* 
 * Function: send_to_thing_speak()
 */
void send_to_thing_speak() {
    // Set the fields with the values
    ThingSpeak.setField(1, temperature);
    ThingSpeak.setField(2, humidity);
    ThingSpeak.setField(3, luxValue);
    ThingSpeak.setField(4, soilMoisturePercent);
    ThingSpeak.setField(5, soilMoistureValue);

    // Set the status message
    myStatus = "[SmartPlant v2] Data updated successfully!";
    ThingSpeak.setStatus(myStatus);

    // Write to ThingSpeak channel.
    int x = ThingSpeak.writeFields(myChannelNumber, myWriteAPIKey);
    delay(1000); // Give some time for the connection to complete
    
    if (DEBUG_MODE){
        // Report result of connection to ThingSpeak
        if (x == 200 || x == 0) {
            Serial.println("[SmartPlant v2] ThingSpeak has been updated.");
        }
        else {
            Serial.println("[SmartPlant v2] ThingSpeak has NOT been updated.");
        }
        delay(intervalPause);
    }
}
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

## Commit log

2024-10-15 added more libraries and ino files. Problem with LDR stuck at 1023.
    [ProteusTest.ino]
2024-10-16 Fixed stuck value in Proteus. Changed to simulino board. Added moisture sensor. Completed ino code.
    [ProteusTest.ino]
2024-10-19 Fixed proteus simulation to include I2C LCD screen
    [ProteusTest2.ino]
2024-10-19 added wire.h library for i2c
2024-10-19 Tested all sensors. All worked but LCD I2C screen. Must test again and fix screen.
    [I2C-Scanner.ino, LCD-I2C-Test.ino, ProteusTest2.ino]
2024-10-20 Fixed LCD. Tested all sensors with ProteusTest2.ino. Ready for second phase.
    [ProteusTest2.ino]
2024-11-29 Added relay inifo
2024-11-29 Added relay info and renamed scripts
2024-11-30 Added relay logic to testing script
2024-11-30 Tested relay with water pump. Updated code to reflect HIGH and LOW state in regards of relay control. Testing script must be tuned to define more permanent setup. Must test water pump to define corre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
    [SmartPlant-Testing.ino]
2024-12-02 Added 3D printable cases for some sensors
    [16x2_back_45deg_m2.stl, 16x2_back_45deg_m3.stl, 16x2_back_90deg_m2.stl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]
2024-12-13 Updated Thingspeak testing script. Tweaked until everything is working live. Connection and posting of data successful. Must move into SmartPlant-testing.
    [Base.stl, Cover.stl, photoresistor_cap.stl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]
2024-12-13 Fixed photoperiod report to ThingSpeak
    [SmartPlant-Testing.ino]
2024-12-15 Inverted calibration values for soil moisture sensor. Deleted LCD reporting when watering plants. Must isolate relay because of interference.
    [SmartPlant-Testing.ino]
2024-12-16 Fixed relay problem. Added LCD reporting when watering plants.
    [SmartPlant-Testing.ino]
2025-01-18 Update calibration extremes for soil moisture value calibration script.
2026-02-19 feat: Add simplified SmartPlant_TempSoil sketch for temp/soil monitoring
    - Created SmartPlant_TempSoil.ino with DHT11 (pin 8) + Soil Moisture (A0)
    - Updated arduino_secrets.h with WiFi credentials (Ardui)
    - Removed LCD, LDR, and relay for simplification
    - Includes ThingSpeak integration for remote monitoring
    - Compiled successfully for Arduino UNO R4 WiFi
2026-04-18 SmartPlant v2: add SmartPlantv2.ino test-bench sketch + update README
    - SmartPlantv2.ino: Arduino Nano test sketch for v2 hardware validation
    - TEMT6000 light sensor on A0 (approximate lux output)
    - AHT10 temp/humidity on I2C (A4/A5, address 0x38)
    - Capacitive soil moisture on A1 (raw analog value)
    - 9600 baud Serial output every 2 seconds
    - README.md: add v2 pin configuration and project structure update
    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
2026-04-18 SmartPlantv2.ino: fix AHT10 temp/humidity conversion formulas
    - Proper 20-bit field extraction: humidity uses data1 + upper 4 bits of data2, shifted right 4
    - Temperature uses lower 4 bits of data2 + data3 + upper 4 bits of data4, shifted right 4
    - Added soft reset (0xBA) before AHT10 init for reliable startup
    - Increased measurement delay to 80ms (was 75ms)
    - Added [E] error indicator when AHT10 read fails (busy bit set)
2026-04-18 SmartPlantv2.ino: add AHT10 raw byte debug output
    Prints raw I2C bytes (s, b1-b4, crc) and extracted humRaw/tempRaw
    in hex on every reading so we can diagnose the conversion formula live.
2026-04-18 SmartPlantv2.ino: fix AHT10 humidity AND temperature extraction
    Correct formulas (verified against all 11 real sensor readings):
    - Humidity: ((b1 << 12) | (b2 << 4)) & 0x0FFFFF — all readings match obs exactly
    - Temperature: ((b2 & 0x0F) << 16) | (b3 << 8) | (b4 & 0xF0) — all readings match
    - The AHT10 uses b2's LOWER nibble for temp[19:16] (not upper nibble)
    - Removed raw byte debug output
2026-04-20 Fixed v2 sensor readings. Ready for wifi module.
2026-04-27 Added v2 version compatible with arduino uno R4 wifi for testing at location.
2026-05-08 Added ESP32 version with led language.
2026-05-12 ESP32-C3: convert TEMT6000 raw ADC to lux (was sending raw counts)
2026-05-12 Added fix for GPIO 2 pin which was producing bad readings.
    [SmartPlantv2-ESP32c.ino]
2026-05-30 Added 3d cases.
    [AHT10.3mf, Box2.stl, Lid2.stl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]

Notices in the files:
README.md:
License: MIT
